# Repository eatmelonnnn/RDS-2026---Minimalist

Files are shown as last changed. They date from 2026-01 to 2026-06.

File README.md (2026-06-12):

# Minimalist Finger

## Assembly Instructions

### 1. Finger Assembly

1. Put bearings into flexion pulleys (3x).
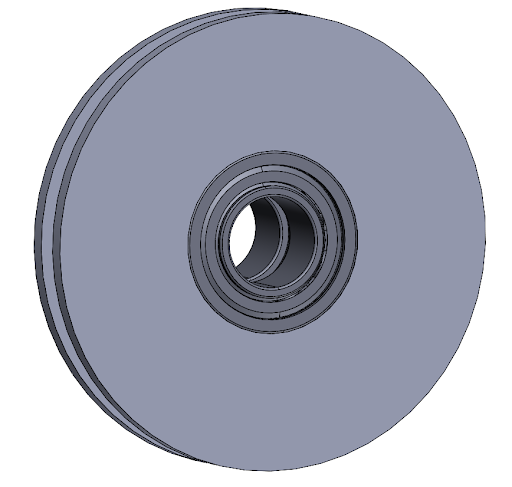
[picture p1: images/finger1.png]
   > 
2. Put bearings and pulleys onto bearing pins (2x).
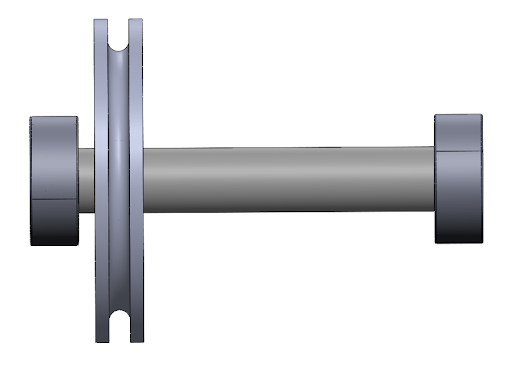
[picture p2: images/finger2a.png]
Step 2a
   > 
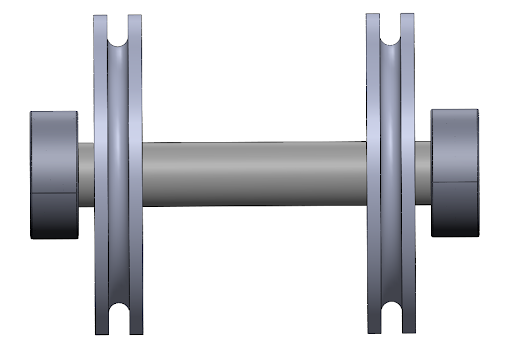
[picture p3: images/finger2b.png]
Step 2b
   > 
3. Tie slipknots onto spring/tendon pins (2x).
4. Snap spring/tendon pin into fingertip and pull tendon into groove.
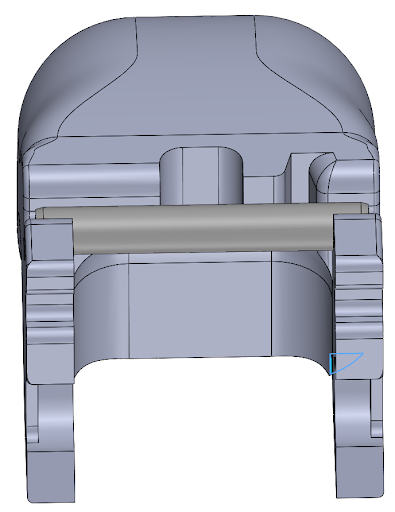
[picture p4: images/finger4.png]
   > 
5. Snap bearing pin into place.
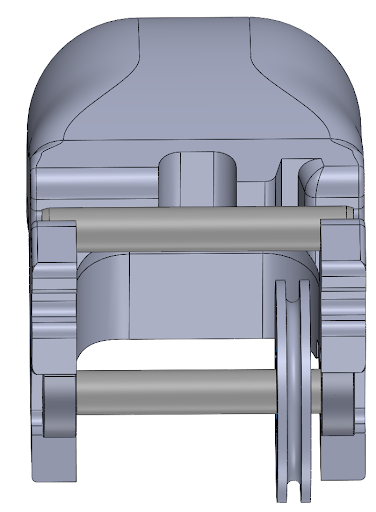
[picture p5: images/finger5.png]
   > 
6. Snap middle linkage onto bearing pin.
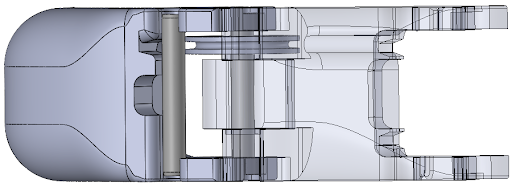
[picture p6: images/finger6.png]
   > 
7. Route tendon through and pull into groove.
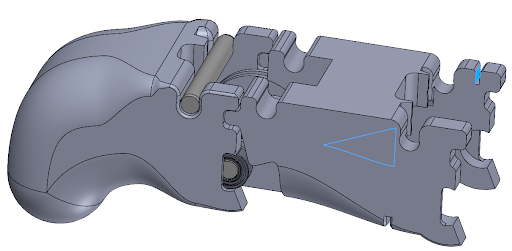
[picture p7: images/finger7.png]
   > 
8. Snap second tendon pin on and pull tendon into groove.
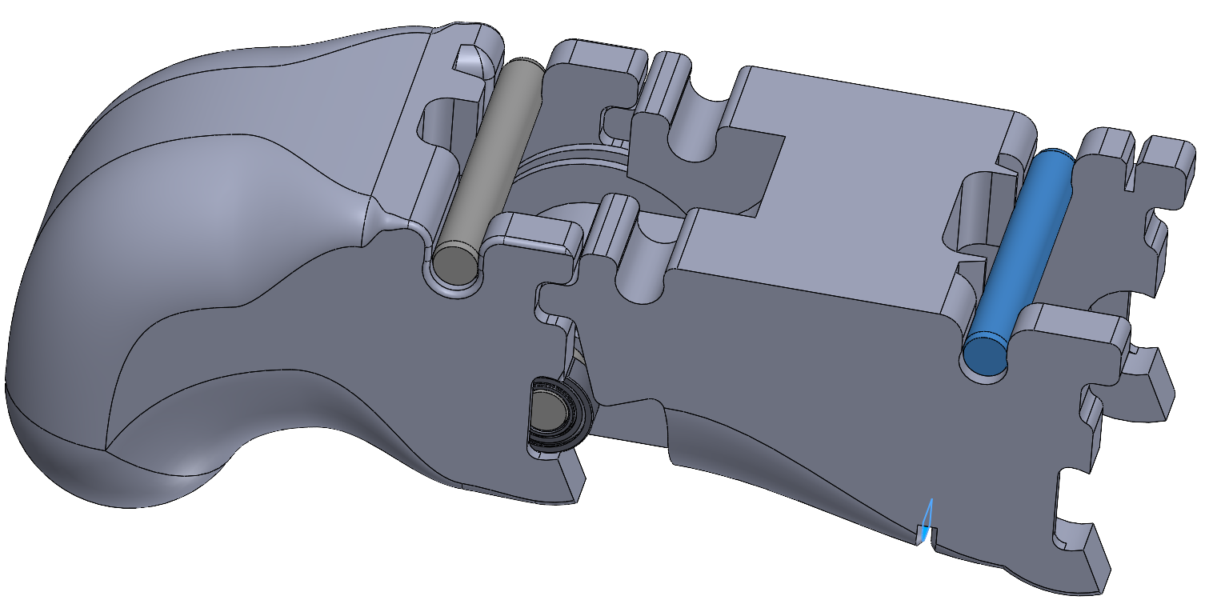
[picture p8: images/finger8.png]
   > 
9. Snap second bearing pin into middle link.
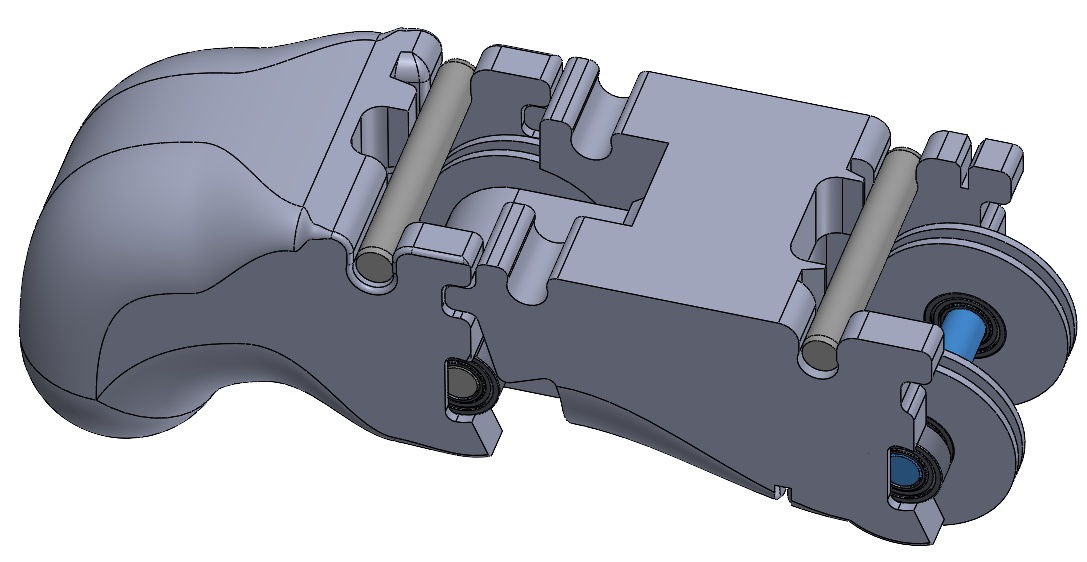
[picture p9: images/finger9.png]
   > 
10. Snap knuckle onto bearing pin.
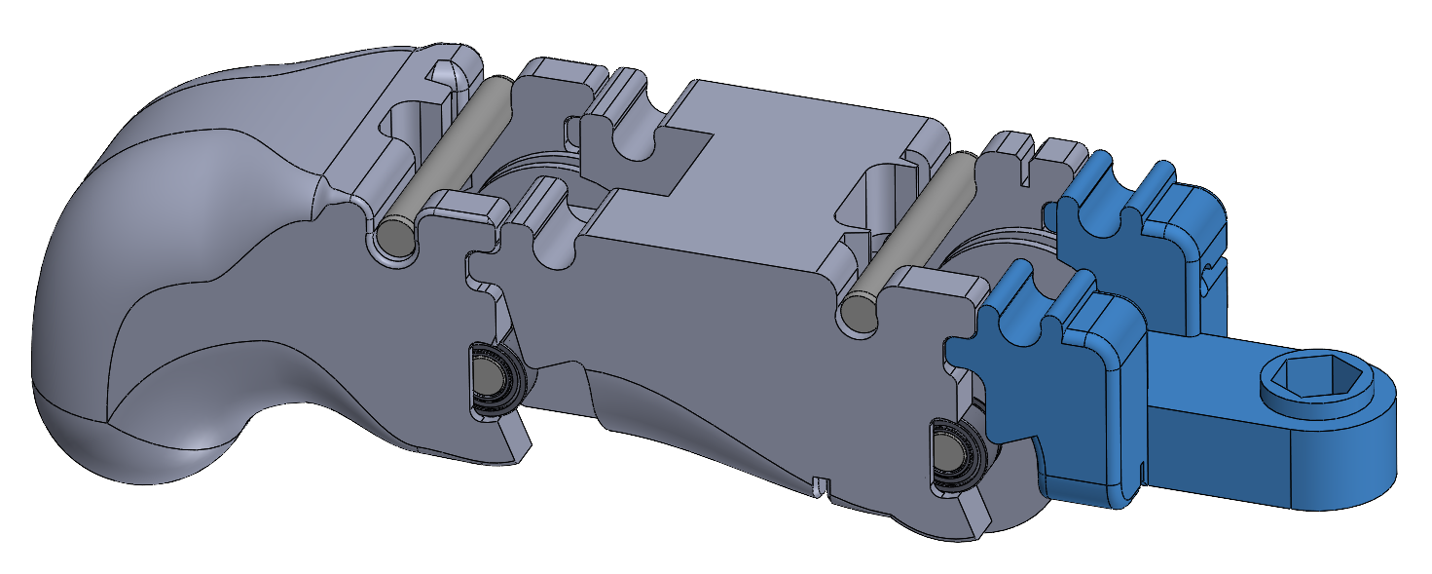
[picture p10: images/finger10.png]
    > 
11. Thread tendons through knuckle and onto grooves.
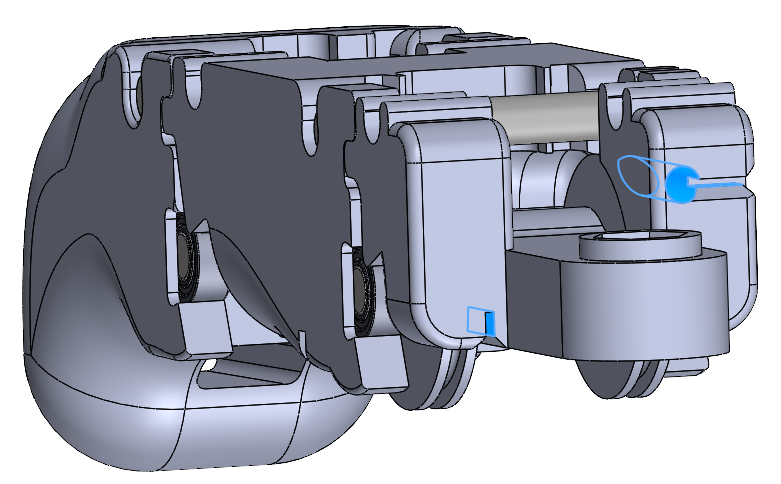
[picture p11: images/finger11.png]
    > 
12. Put bearings into splay pulleys (2x).
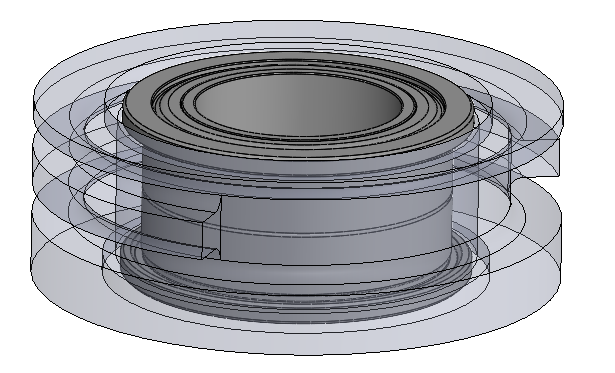
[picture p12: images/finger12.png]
    > 
13. Put belt pulley onto shaft.
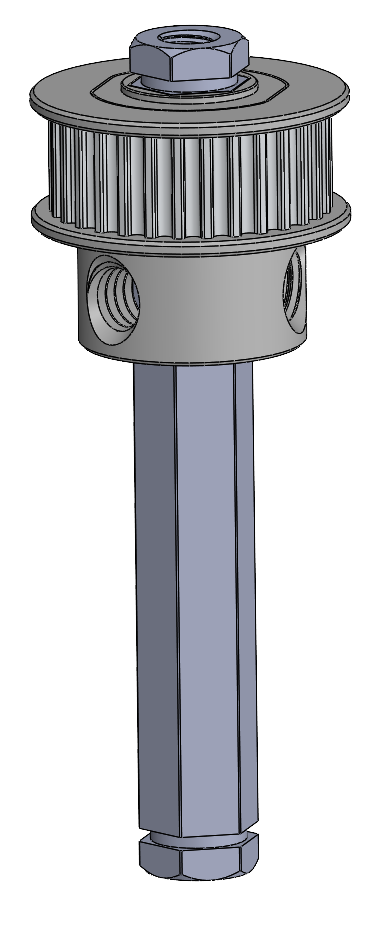
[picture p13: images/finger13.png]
Step 13
    > 
14. Align all splay components and push shaft through.
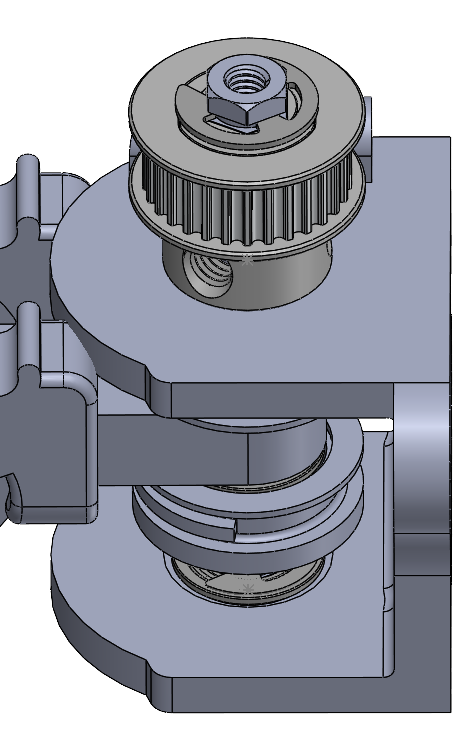
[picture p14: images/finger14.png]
Step 14
    > 
15. Wrap tendons around splay pulleys and thread through base.
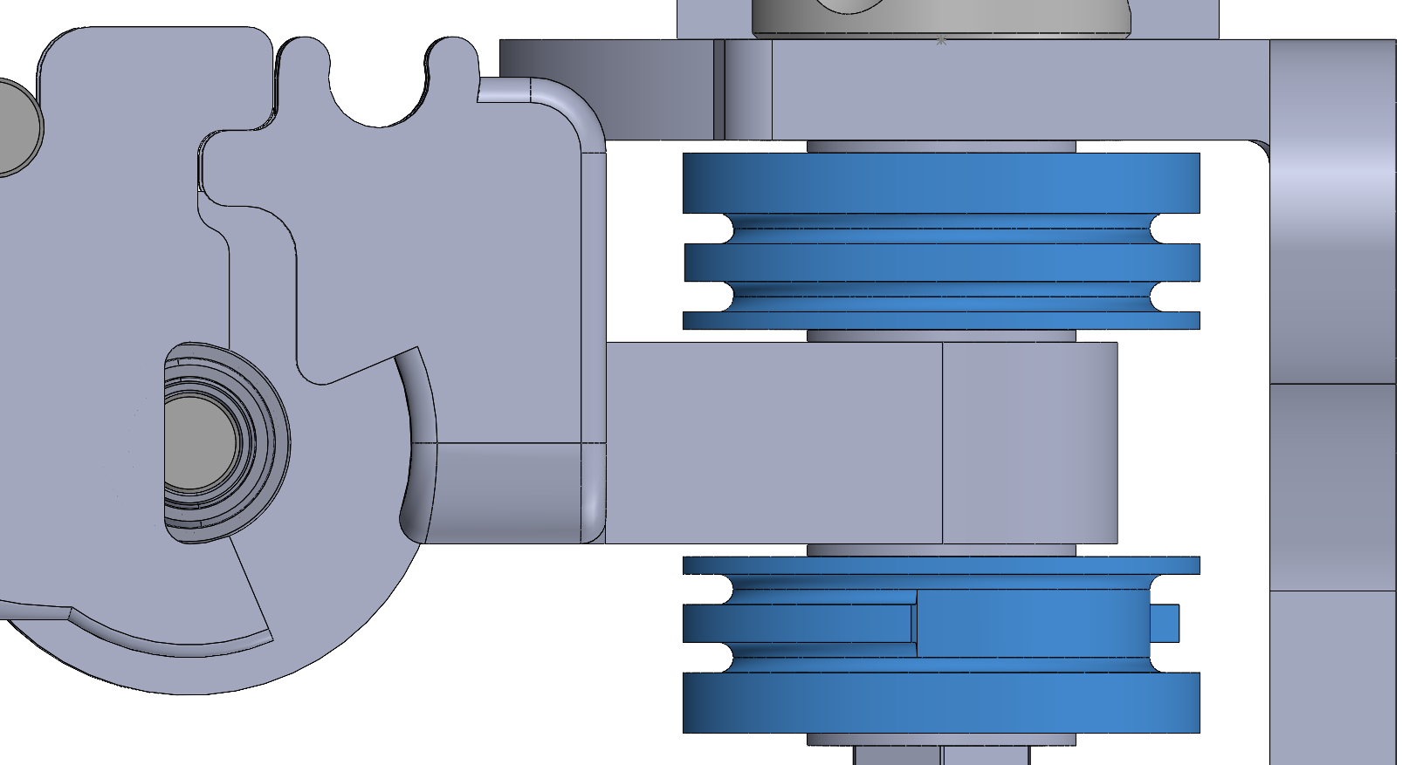
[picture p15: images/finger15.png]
Step 15
    > 
16. Put springs onto pins and snap onto linkages (x2).
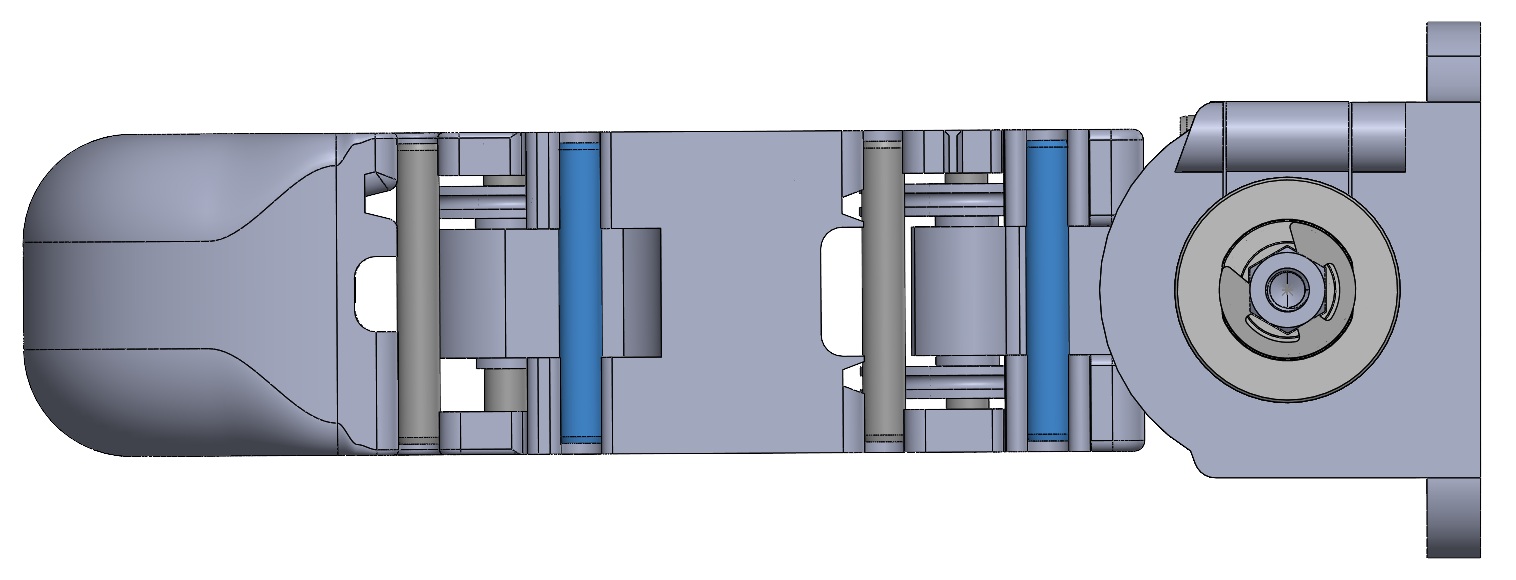
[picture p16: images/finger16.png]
Step 16
    > 
17. Gently pry up tendon/spring pins and loop springs on (x2).
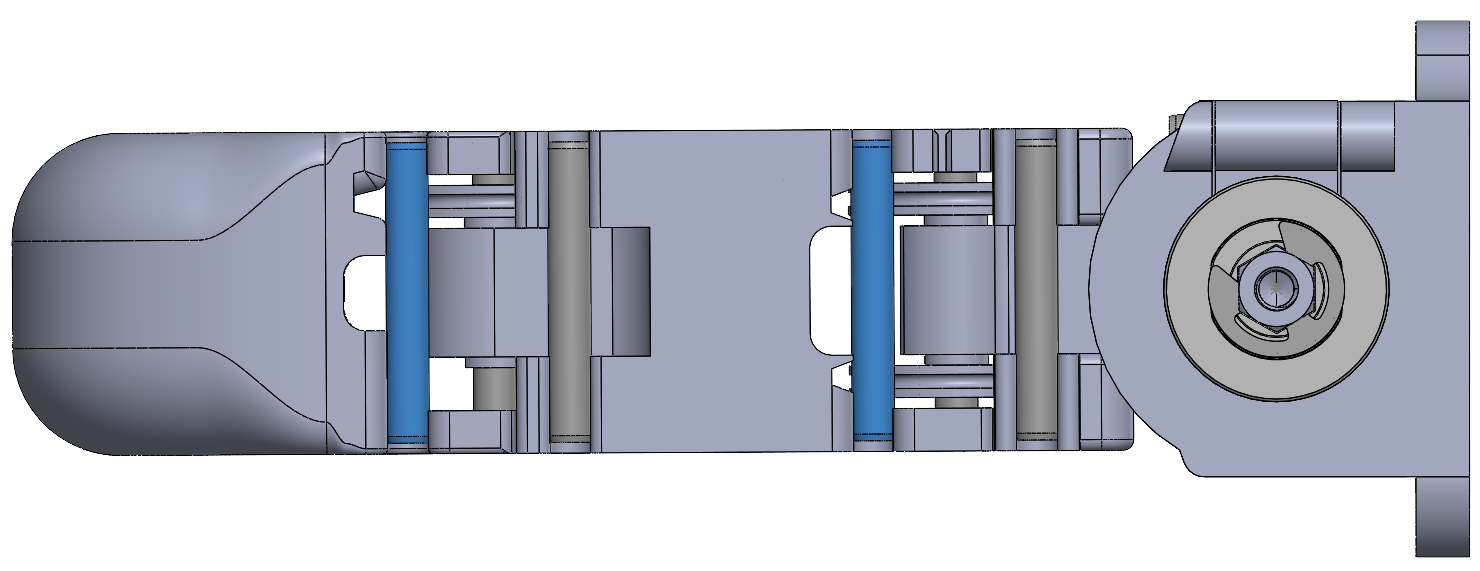
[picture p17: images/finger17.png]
Step 17
    > 

---

##3 2. Mounting Assembly

1. Assemble main 80-20 frame with plates and bolts.
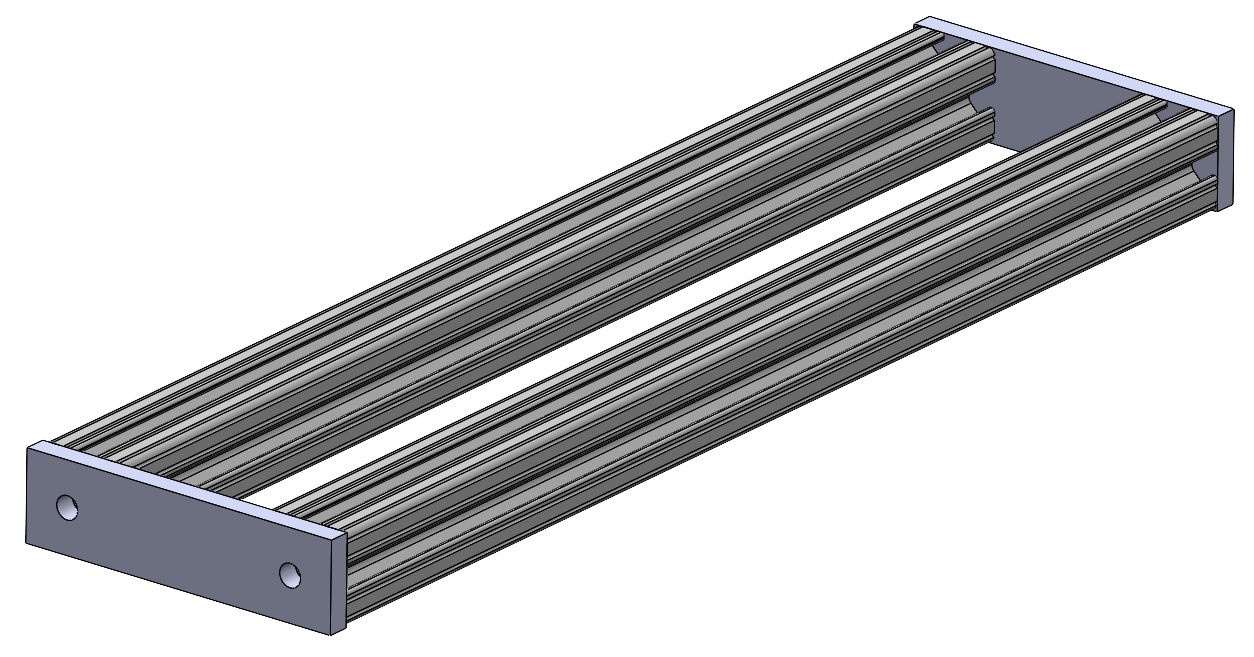
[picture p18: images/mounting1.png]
   > 
2. Put vertical 80-20 on with brackets and bolts.
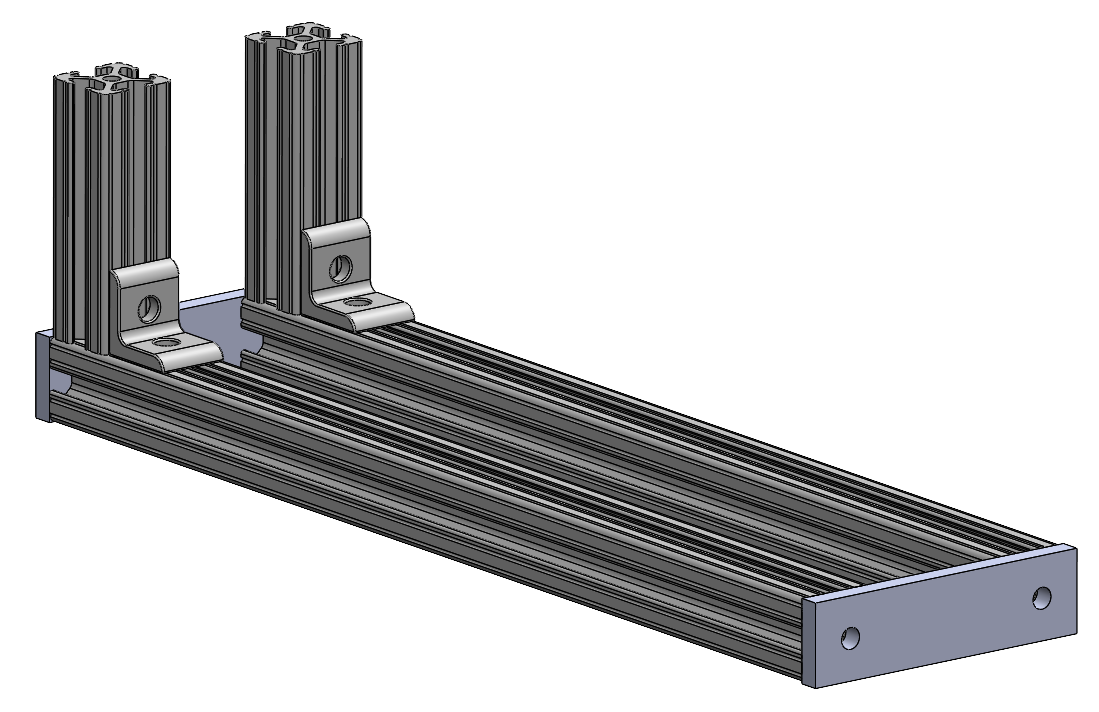
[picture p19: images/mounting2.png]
   > 
3. Put pulley on splay motor.
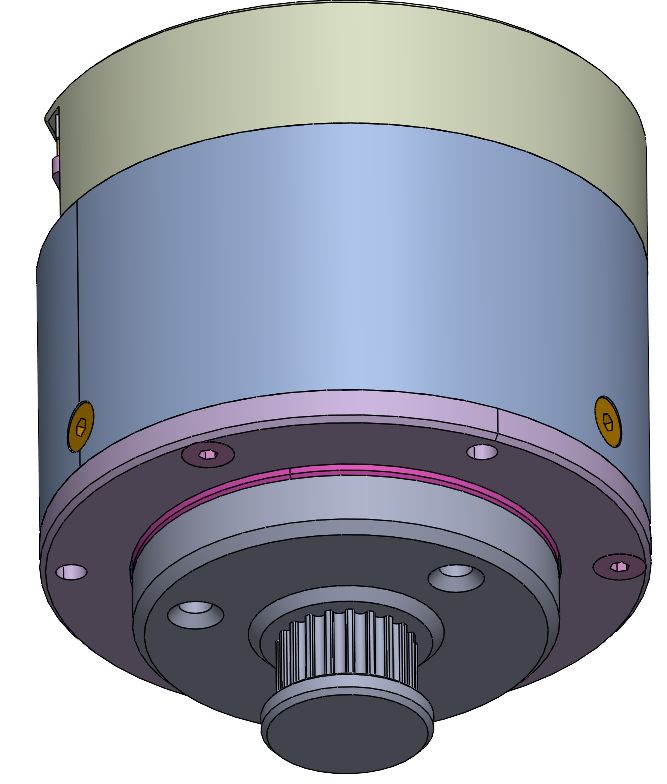
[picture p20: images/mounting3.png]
   > 
4. Put splay motor on splay plate.
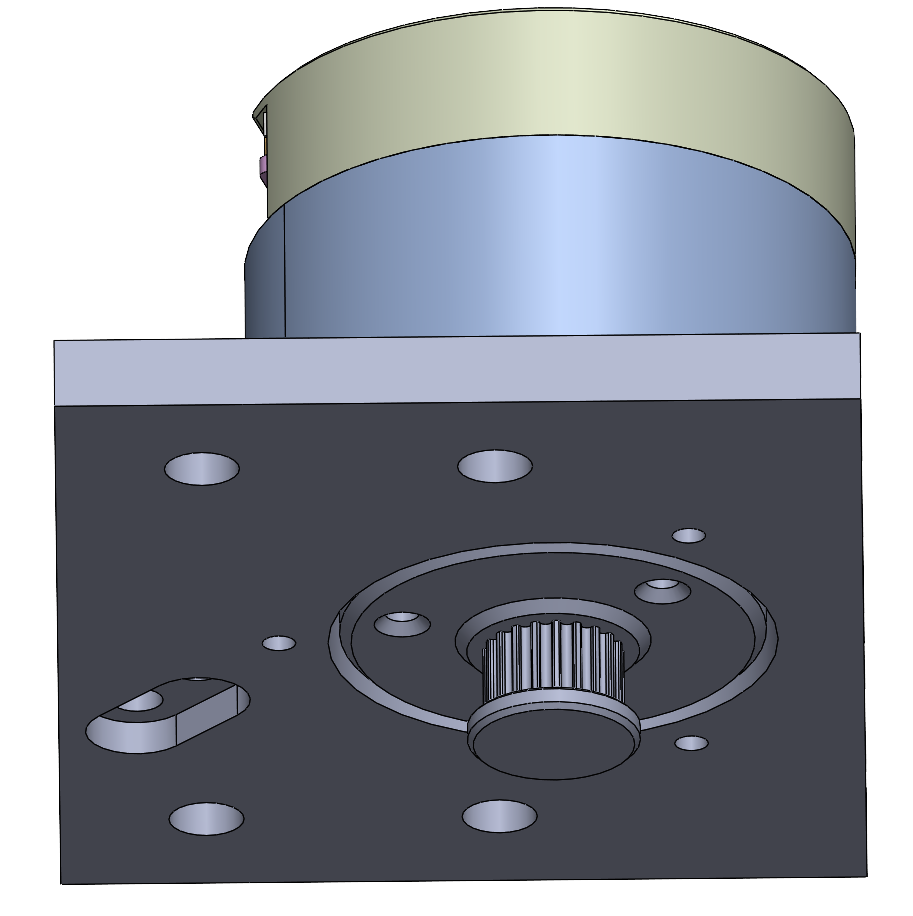
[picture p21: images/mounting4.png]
   > 
5. Put tensioner on splay plate.
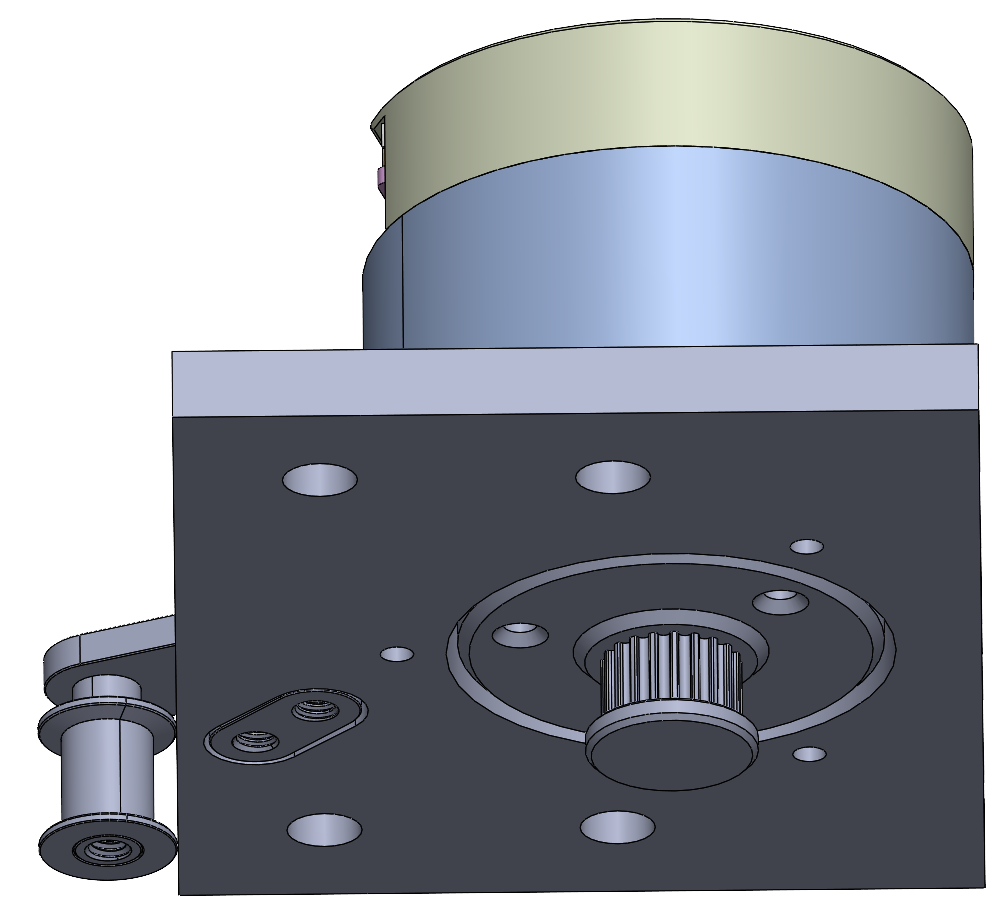
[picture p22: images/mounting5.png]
   > 
6. Put splay plate on vertical 80-20 with brackets and bolts.
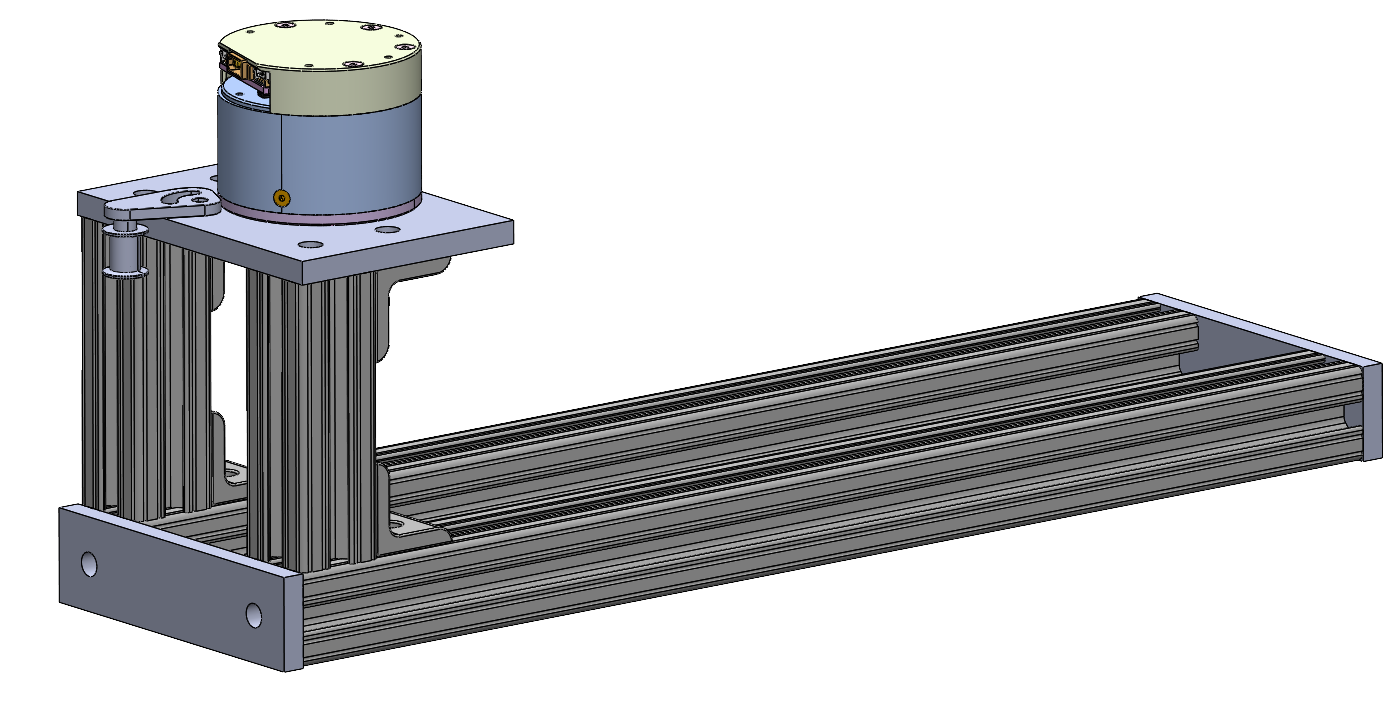
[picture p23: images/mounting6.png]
   > 
7. Put finger plate on vertical 80-20 with bolts.
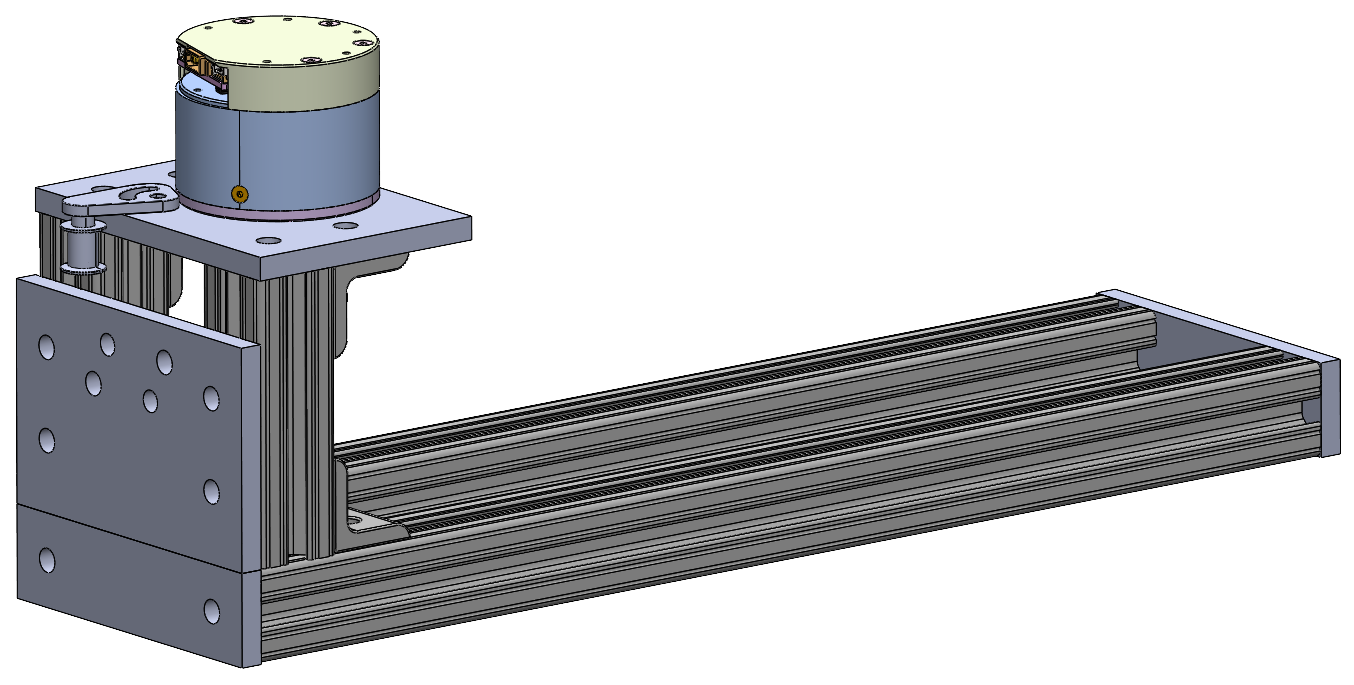
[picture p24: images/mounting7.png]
   > 
8. Put tension plates on 80-20 with bolts (2x).
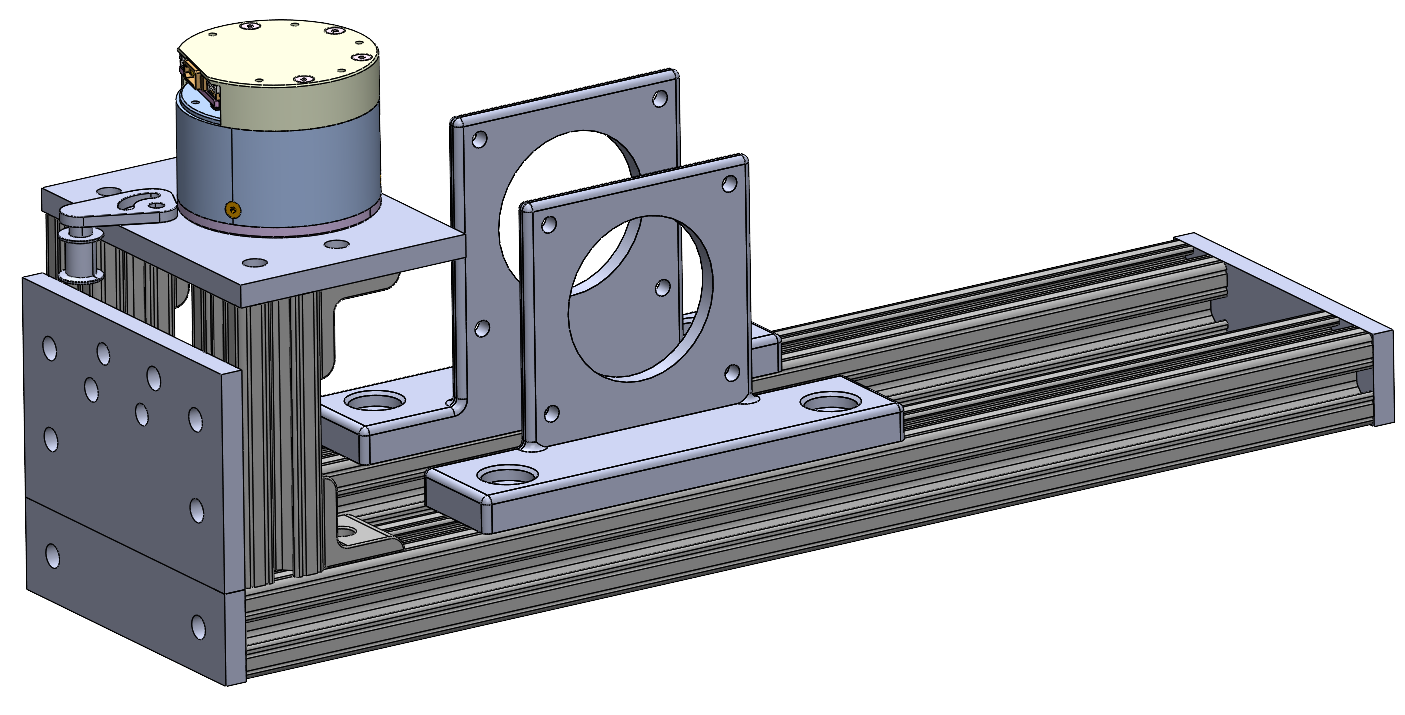
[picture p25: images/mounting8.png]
   > 
9. Put motor plates on 80-20 with bolts (2x).
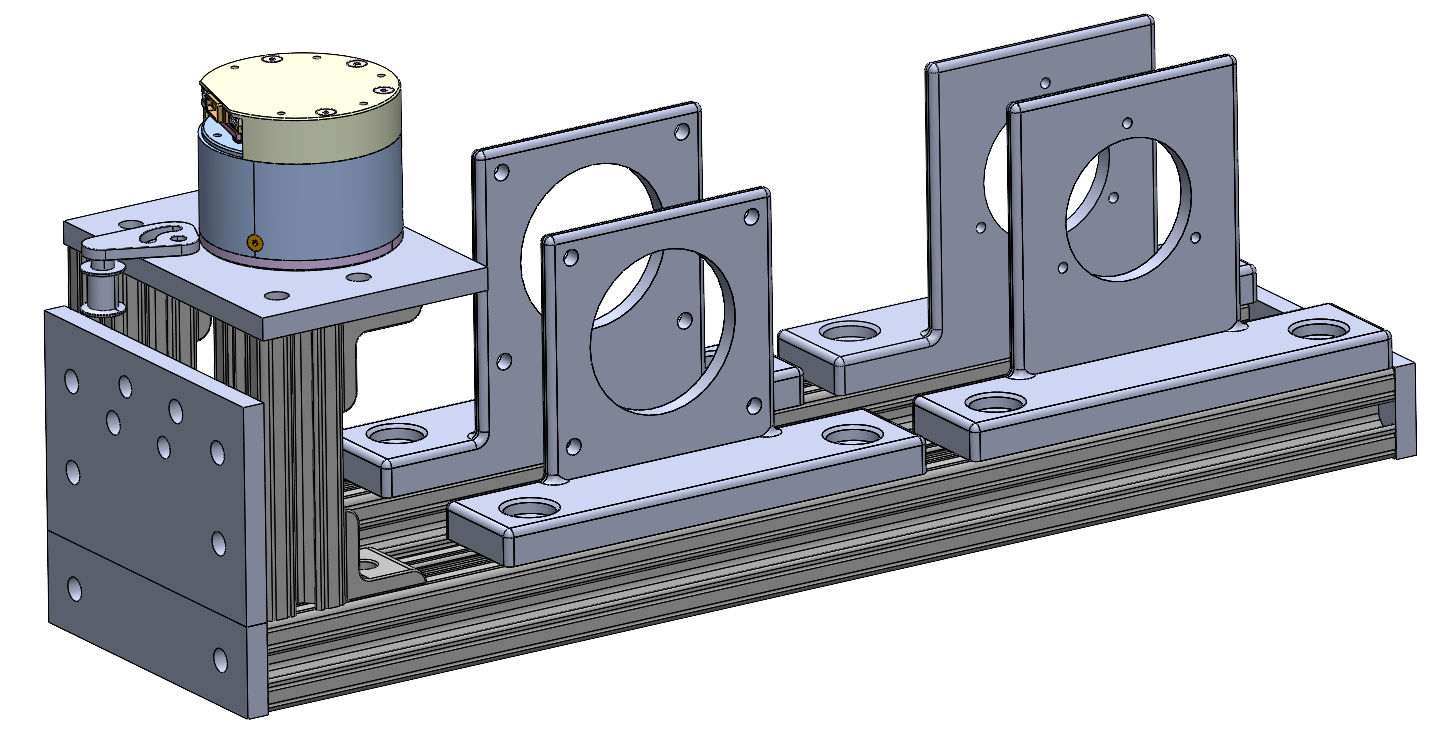
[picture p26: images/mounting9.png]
   > 
10. Put pulleys on flexion motors (2x).
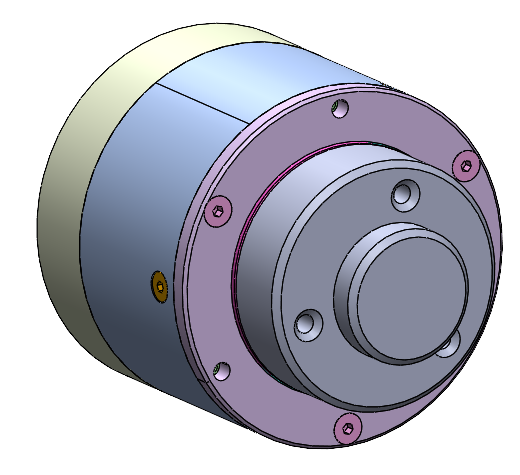
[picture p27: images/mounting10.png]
    > 
11. Put tension sensors on tension plates (2x).
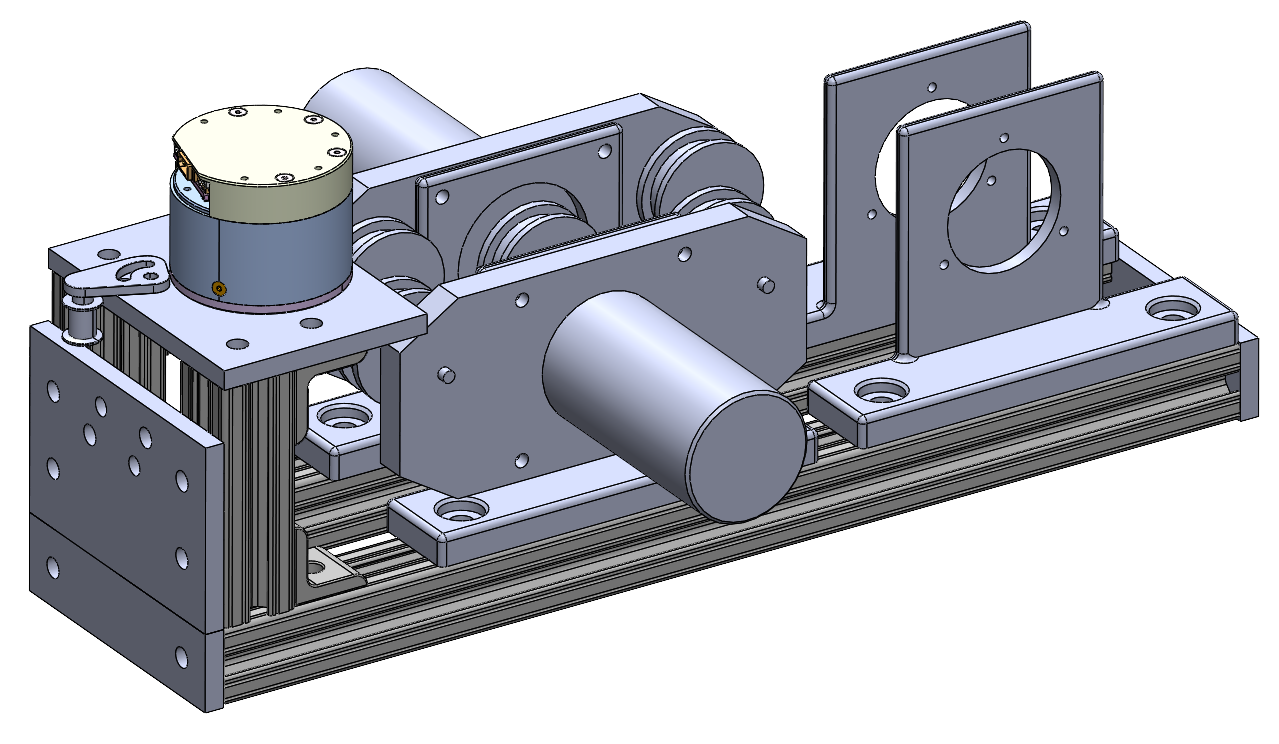
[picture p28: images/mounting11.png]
    > 
12. Put motors on motor plates (2x).
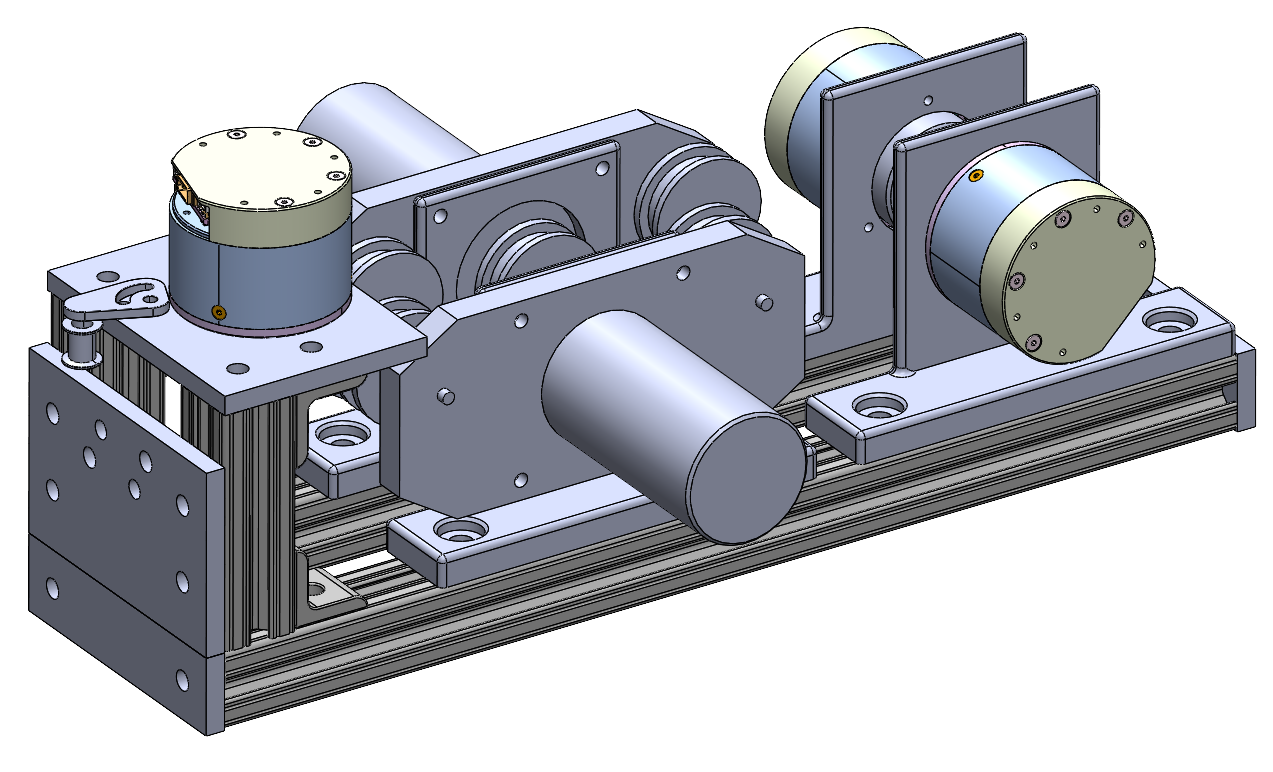
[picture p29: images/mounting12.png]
    > 

---

### 3. Finger/Mounting Integration Assembly

1. Bolt finger onto plate and put splay belt on.
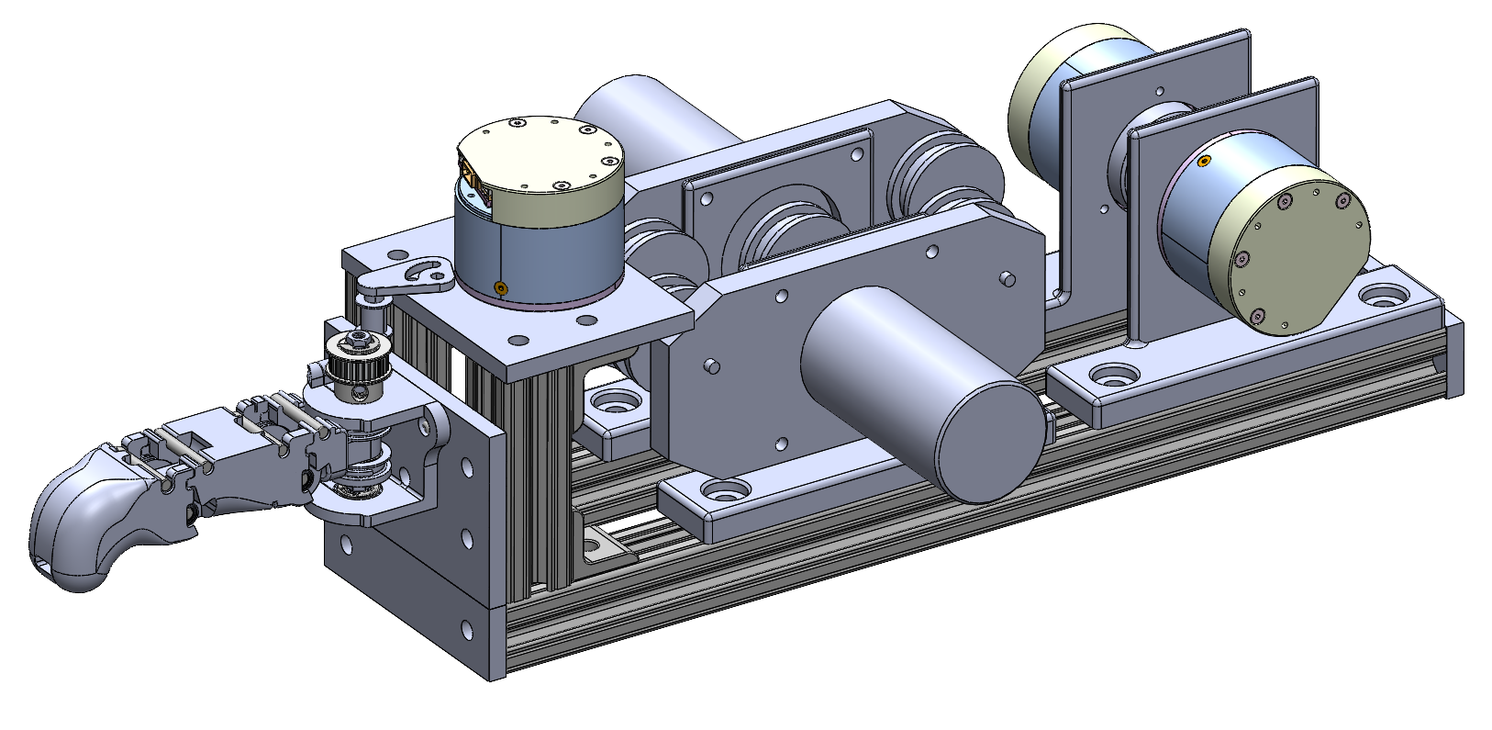
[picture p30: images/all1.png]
   > 
2. Tension splay belt with allen key.
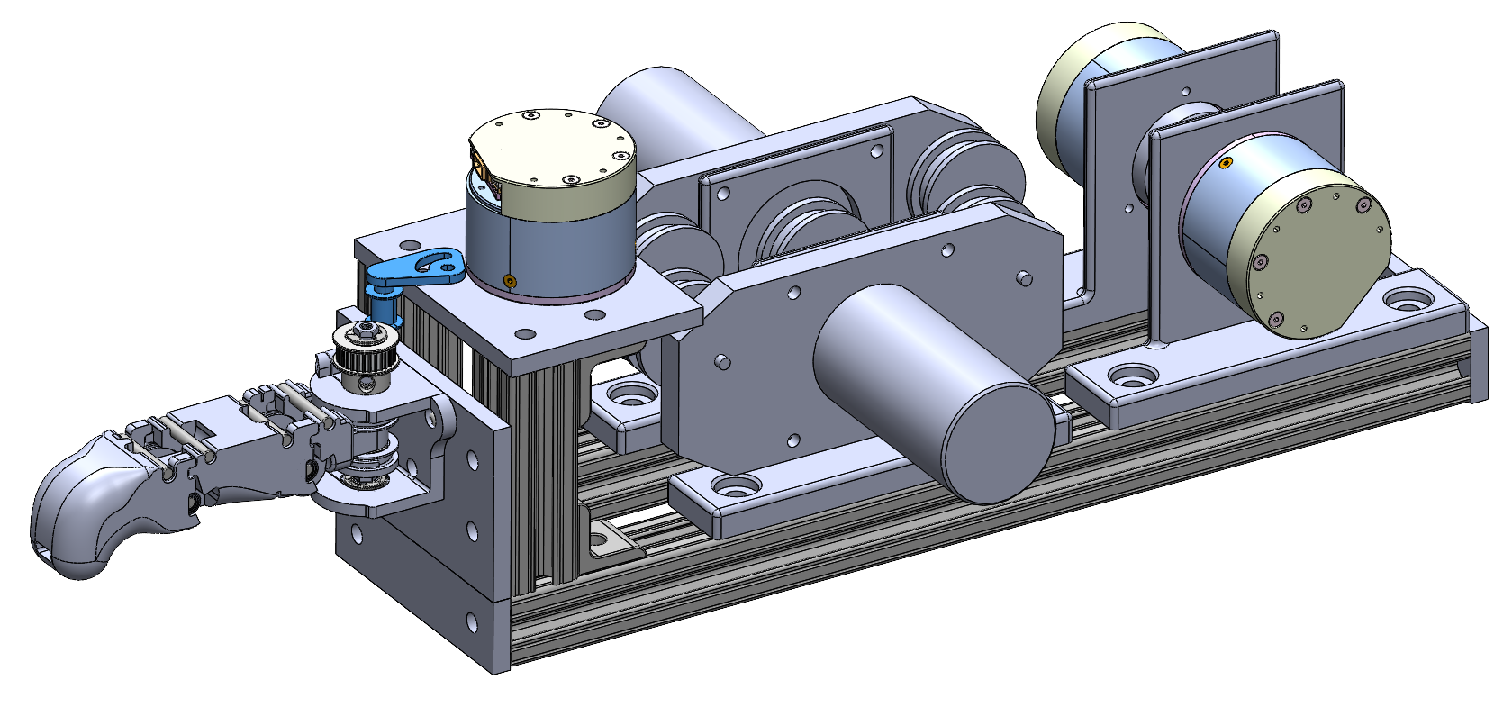
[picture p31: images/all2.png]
   > 
3. Thread tendon from finger through tension sensor and onto pulley.
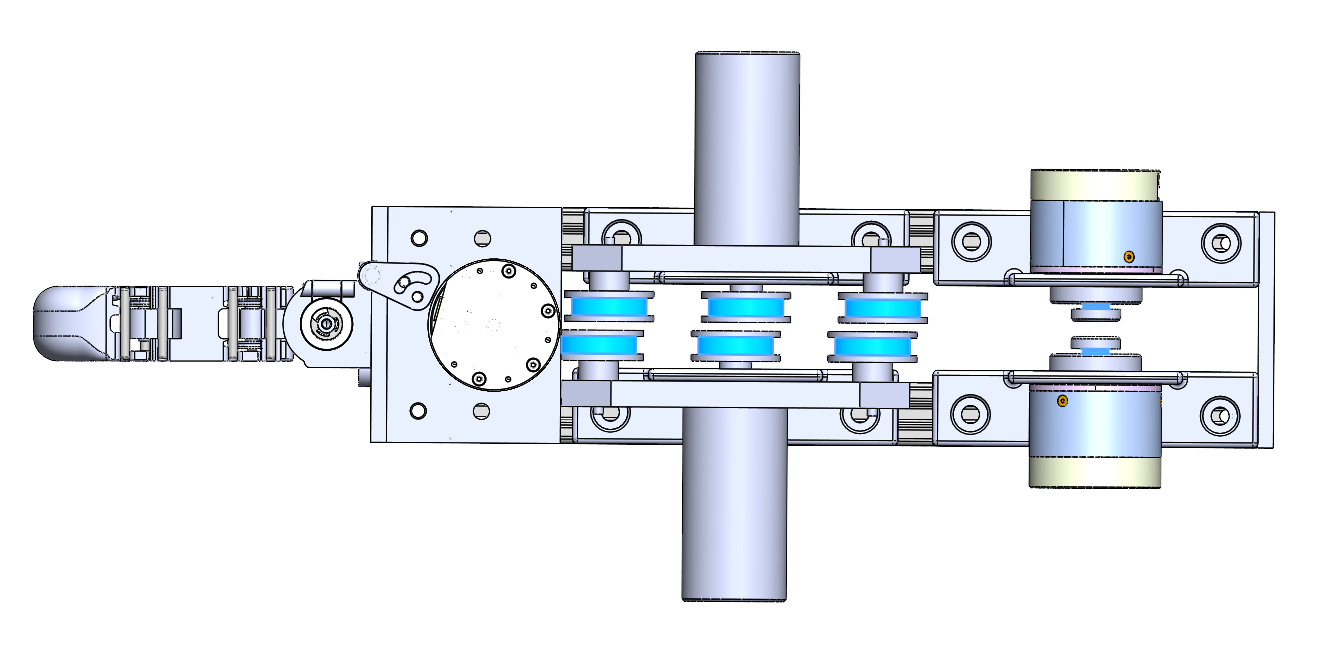
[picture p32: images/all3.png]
   > 
4. Terminate tendon on motor pulley with slipknot and screw.

---
## Instructions to Run Finger Program/Operate Finger Once Assembled

1. Locate main folder in the Electrical and upload `main.ino` to the Teensy 4.1.

2. Let calibration sequence run without interference.

3. Choose desired behavior/test.
   - For all states except the flexion-extension test, simply press the specified button to trigger the state switch.
   - You can switch between any two states by pressing the corresponding buttons.
   - For the MCP flexion-extension test:
     - Move the jumper wire on Pin 33 from **GND** to **3.3V**.
     - This will trigger the flexion-extension test.
     - At this point, there is no way to return to the other states without rerunning the program from the start on the Teensy.

4. When finished, press the **E-stop** to turn off the motors.

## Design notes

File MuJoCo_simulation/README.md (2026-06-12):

# Finger Flick — MuJoCo Simulation

A MuJoCo C++ simulation in which a 3-DOF tendon driven robotic finger actively **flicks a
swinging pendulum**. A ball hangs from a hinged rod and swings back and forth; a
controller watches the rod angle and velocity and, at the right moment, curls the
finger to swat the ball as it approaches. The scene renders in an interactive 3D
window with mouse-controlled camera.

This project uses the **native MuJoCo C/C++ API** with **GLFW** for windowing and
rendering — not the Python bindings.

---

## Contents

| File | Purpose |
|---|---|
| `pendulum_test.cpp` | Simulation loop, controller state machine, and GLFW/MuJoCo rendering. |
| `test.xml` | MuJoCo MJCF model: the finger, the pendulum, actuators, and a start keyframe. |
| STL meshes | `base_link.STL`, `splay_link.STL`, `mcp_link.STL`, `pip_link.STL` can be accessed in the MuJoCo_simulation/finger_workspace/src/finger_description/meshes directory. |

---

## What the simulation does

### The model (`test.xml`)

The world contains two independent mechanisms:

**1. The finger** — a serial chain of three actuated joints mounted to a fixed base:

- `splay_joint` — sideways spread (axis Z), sprung and damped, held at 0 by the controller.
- `mcp_joint` — the "knuckle" (MCP), range ±1.57 rad.
- `pip_joint` — the middle joint (PIP), range ±1.57 rad. The PIP link carries a
  capsule collision geom (`pip_geom`) — this is the part that actually strikes the ball.

Each joint is driven by a MuJoCo **`position` actuator** with a proportional/derivative
gain (`kp`/`kv`), so writing a target angle to `d->ctrl[i]` servos that joint toward it.

**2. The pendulum** — a non-colliding support box with a hinged rod hanging below it
and a sphere (`ball_geom`) at the rod's tip. The hinge is almost frictionless
(`damping="0.00025"`), so once released it swings freely under gravity.

Other model settings worth knowing:

- Gravity `-9.81`, timestep `0.001 s`, implicit integrator, contact enabled.
- A keyframe named **`start`** sets the initial pose `qpos = "0 0 0 -1.4"`
  (splay, MCP, PIP at 0; rod pulled back to −1.4 rad so it swings in on release).
- Contact parameters (`solref`, `solimp`, `friction`) are tuned on `pip_geom` and
  `ball_geom` so the strike reads as a crisp swat.

The generalized coordinates are, in order:
`qpos[0]=splay`, `qpos[1]=MCP`, `qpos[2]=PIP`, `qpos[3]=rod hinge`.

### The controller (`pendulum_test.cpp`)

The main loop steps the physics once per iteration (and sleeps to keep the sim
roughly real-time), reads joint states, then runs a three-state machine that drives
the finger:

- **READY** — finger held open. It waits until the rod swings past a trigger angle
  while moving toward the finger, then transitions to FLICK.
- **FLICK** — commands the MCP and PIP joints to curl (targets `0.8` and `1.2` rad)
  for a short burst (~0.1 s) to swat the ball.
- **RESET** — returns the finger to open and holds for ~0.4 s before re-arming.

Alongside the state machine, the loop checks `d->contact[...]` every step for a
collision between `pip_geom` and `ball_geom` to flag when an actual hit occurs.
Every 50 steps it prints the current state, rod angle/velocity, and joint angles to
the console; every 10 steps it redraws the window.

> **Tuning:** the trigger angle, approach-velocity threshold, flick/reset durations,
> and the curl targets are all `const` knobs near the top of the loop. Adjust them
> while watching the printed `Rod` values to dial in the timing for your build.

### Interactive controls

| Input | Action |
|---|---|
| Left-drag | Rotate camera |
| Right-drag | Pan camera |
| Shift + drag | Alternate rotate/pan axis |
| Scroll | Zoom |
| Esc | Quit |

---

## Prerequisites

- A C++17 compiler (GCC, Clang, or MSVC).
- **MuJoCo** (the C/C++ library). Version 3.x is recommended — see install below.
- **GLFW 3** development libraries.
- **OpenGL** (present on essentially all desktop systems).
- **CMake** ≥ 3.16 (recommended for the build).

---

## Installing MuJoCo

MuJoCo is open source (Apache-2.0, maintained by Google DeepMind). For C/C++ work the
easiest route is the **prebuilt library release** — there is no installer; it ships as
a single archive (`.tar.gz` on Linux, `.dmg` on macOS, `.zip` on Windows).

1. Go to the MuJoCo GitHub releases page:
   <https://github.com/google-deepmind/mujoco/releases>
2. Download the latest release for your platform (3.2.7 or newer at time of writing).
3. Extract it somewhere stable, e.g. `~/.mujoco/mujoco-3.x.x/`. You should end up with
   `include/` (headers) and `lib/` or `bin/` (the shared library).

> If you prefer, you can also build MuJoCo from source (needs CMake + a C++17
> compiler), but the prebuilt library is recommended unless you intend to modify
> MuJoCo's core.

### GLFW

- **Ubuntu/Debian:** `sudo apt install libglfw3-dev`
- **macOS (Homebrew):** `brew install glfw`
- **Windows:** download from <https://www.glfw.org/> or install via `vcpkg install glfw3`.

---

## Project layout and file paths

⚠️ **The paths in the source are relative and must line up, or the model won't load.**

- `pendulum_test.cpp` loads the model from `../../finger_description/urdf/test.xml`.
- `test.xml` in turn references its meshes at `../meshes/*.STL`.

So the model and meshes are expected to live like this, with the executable run from a
directory **two levels below** the parent of `finger_description/`:

```
project/
├── finger_workspace/
│   ├── urdf/
│   │   └── test.xml
│   └── meshes/
│       ├── base_link.STL
│       ├── splay_link.STL
│       ├── mcp_link.STL
│       └── pip_link.STL
└── finger_controller/
    └── pendulum_test     # run from here → ../../finger_description/urdf/test.xml
```

If your layout differs, either move the files to match, or edit the path in the
`mj_loadXML(...)` call (and the mesh paths in `test.xml`) accordingly. Using absolute
paths while you get it running first is a reasonable shortcut.

---

## Building

### Option A — CMake (recommended)

Create a `CMakeLists.txt` next to `pendulum_test.cpp`:

```cmake
cmake_minimum_required(VERSION 3.16)
project(finger_flick CXX)

set(CMAKE_CXX_STANDARD 17)
set(CMAKE_CXX_STANDARD_REQUIRED ON)

# Point this at your extracted MuJoCo directory
set(MUJOCO_DIR "$ENV{HOME}/.mujoco/mujoco-3.2.7" CACHE PATH "MuJoCo root")

find_package(glfw3 REQUIRED)
find_package(OpenGL REQUIRED)

add_executable(pendulum_test pendulum_test.cpp)

target_include_directories(pendulum_test PRIVATE
    ${MUJOCO_DIR}/include
    ${CMAKE_CURRENT_SOURCE_DIR})      # so kinematics.h is found

target_link_directories(pendulum_test PRIVATE ${MUJOCO_DIR}/lib)

target_link_libraries(pendulum_test PRIVATE
    mujoco
    glfw
    OpenGL::GL)
```

Then build:

```bash
mkdir -p build && cd build
cmake .. -DMUJOCO_DIR=/path/to/mujoco-3.2.7
cmake --build .
```

### Option B — direct compile (Linux)

```bash
g++ -std=c++17 pendulum_test.cpp -o pendulum_test \
    -I/path/to/mujoco/include -I. \
    -L/path/to/mujoco/lib -lmujoco -lglfw -lGL
```

On Linux you may also need the library on the loader path at runtime:

```bash
export LD_LIBRARY_PATH=/path/to/mujoco/lib:$LD_LIBRARY_PATH
```

(macOS uses `DYLD_LIBRARY_PATH`; on Windows, place `mujoco.dll` next to the
executable or add its folder to `PATH`.)

---

## Running

From the directory that makes the relative model path resolve (see **Project layout**):

```bash
./pendulum_test
```

You should see:

- A console message confirming the `start` keyframe loaded.
- A 3D window with the floor, the finger, and the swinging ball pendulum.
- Periodic console output like:

  ```
  State: READY  | Rod: -1.182 (vel 0.642) | MCP: 0.000 PIP: 0.000
  Ball approaching = 1
  ```

The ball swings in, the finger flicks, and the loop re-arms. Drag with the mouse to
orbit the camera; press **Esc** to quit.

---

## Troubleshooting

- **`Error loading model: ...`** — the XML path or a mesh path is wrong. Confirm the
  directory layout above, or hard-code an absolute path in `mj_loadXML`.
- **`Keyframe not found`** — the model loaded but the `start` key is missing or renamed;
  the sim still runs, just from the default pose.
- **Linker errors for `mj_*` / `mjv_*` / `mjr_*`** — MuJoCo include/lib paths are wrong,
  or `-lmujoco` is missing.
- **Linker errors for `glfw*`** — GLFW dev package not installed or not linked.
- **`cannot open shared object file: libmujoco...`** at runtime — set
  `LD_LIBRARY_PATH` (Linux) / `DYLD_LIBRARY_PATH` (macOS), or put the DLL beside the
  exe (Windows).
- **`kinematics.h: No such file or directory`** — supply that header and make sure its
  directory is on the include path (`-I.` or `target_include_directories`).
- **The finger never flicks / always misses** — tune `flick_trigger_angle`, the
  `rod_vel` threshold, and `flick_duration` while watching the printed `Rod` values.

---

## Notes & references

- MuJoCo docs: <https://mujoco.readthedocs.io/>
- MuJoCo releases: <https://github.com/google-deepmind/mujoco/releases>

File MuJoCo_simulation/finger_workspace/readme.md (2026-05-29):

### Opening mujoco viewer
1. Ensure you are in the folder that contains finger.xml
2. python3 -m mujoco.viewer --mjcf=finger.xml

## Run virtual environmnent
source /mujoco_env/bin/activate     # have to create in that directory first

## Check STL number of faces
python3 -c "
from stl import mesh
import os

for f in os.listdir('.'):
    if f.endswith('.STL') or f.endswith('.stl'):
        m = mesh.Mesh.from_file(f)
        print(f'{f}: {len(m.vectors)} faces')
"

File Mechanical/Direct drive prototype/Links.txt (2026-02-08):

Spiral bevel gear: https://catalog.khkgears.us/item/bevel-gears/spiral-bevel-gears-sbs/sbs1-4020r
Spiral bevel pinion: https://catalog.khkgears.us/item/bevel-gears/spiral-bevel-gears-sbs/sbs1-2040l

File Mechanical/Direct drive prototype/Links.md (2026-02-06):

1. **maxon for motor selection:**

https://www.maxongroup.us/maxon/view/category?\_gl=1\*1xv3u2h\*\_gcl\_au\*MTE0MzA2OTMzNC4xNzY4NDEwNjE2\*\_ga\*NTQzNzM2MDA3LjE3Njg0MTA2MTc.\*\_ga\_TKST59FCFB\*czE3Njg0MTA2MTYkbzEkZzEkdDE3Njg0MTA2NTkkajE3JGwwJGgw

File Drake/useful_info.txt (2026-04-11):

Open virtual environment:
-------------------------
- open ubuntu 22.04
- got to base directory cd /
- run: source /drake_env/bin/activate     (exit -> to deactivate)

Convert from obj to sdf:
-----------------------
- make sure you are in the virtual environment
- to get more details run: python3 -m pydrake.multibody.mesh_to_model --help
- run: python3 -m pydrake.multibody.mesh_to_model path/to/mesh.obj (basic no mass specification)
- note if scale used is not meters, you have to specify scale
- variables that can be specified: 
	- mesh_to_model.py [-h] [--model-name NAME] [--scale FACTOR] [--density KG/M3 | --mass KG] 
			[--origin-at-com | --body-origin X,Y,Z]
                        [--package ENCODING] [--output-dir OUTPUT_DIR]
                        mesh_path
- Note: I got an error when I used a 0.001 scale for mm so for now just ignore scale

Drake PID Controller:
--------------------
2 inputs: desired state, estimated state
1 output: control signal (fed into the plant)

Control signal: y = p_y*(kp*(qd-qc) + kd*(vd-vc)+ ki*integral(qd-qc))
		qd: desired position
		qc: controlled position
		vd: desired velocity
		vc: controlled velocity

Changes made to assembly:
--------------------
The main assembly of the finger is fully represented in the simulation, only spacers and retainers are not included due to their small weight and minimal influence to the system.

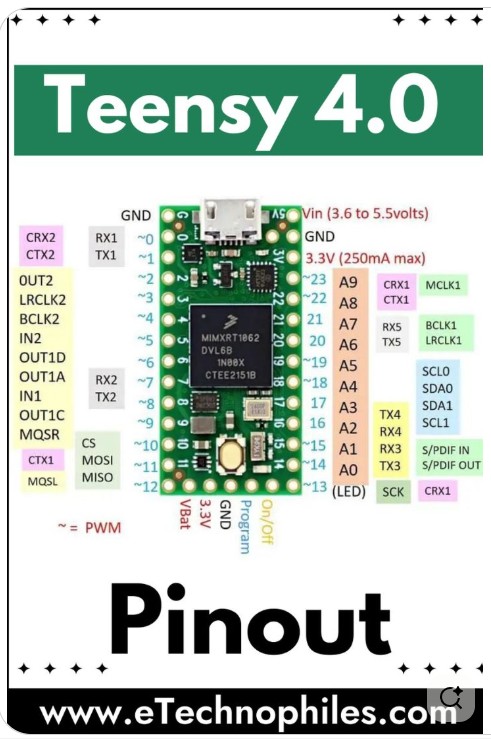
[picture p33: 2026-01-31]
Electrical/Warmup Project/Electrical Diagrams/Circuit diagrams kicad/Teensy_pinout.jpg

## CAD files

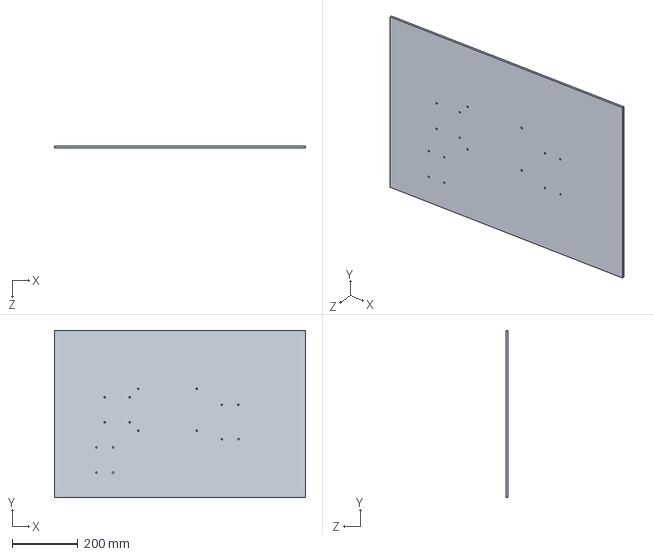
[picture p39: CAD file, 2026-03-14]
Mechanical/Full assembly parts/base_plate_full_assembly.SLDPRT
762.0 x 508.0 x 6.00 mm

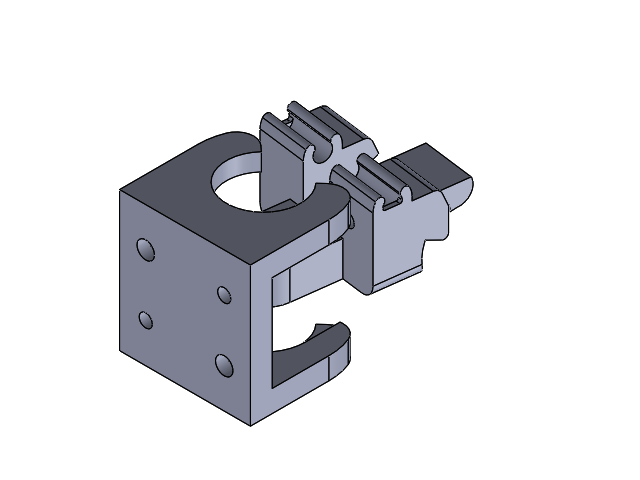
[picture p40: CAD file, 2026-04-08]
Drake/minimalist finger sldrt/Assem1.SLDASM
FingerBase
FingerMCP

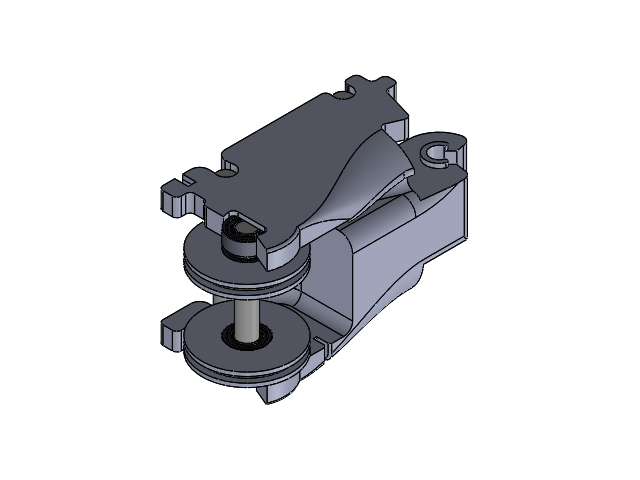
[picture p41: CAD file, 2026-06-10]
Mechanical/Assemblies/Link parts for simulation/mcp_flexion.SLDASM
FingerLinkExperimental_1
inner_ring_71 x 4
outer_ring_172 x 4
bearing_ball_65 x 36
sheild_67 x 8
metal_cage_56 x 4
_001_miniature_ball_bearing_inch x 4
91585A465_18-8 Stainless Steel Dowel Pin_1 x 3
Flexion Tendon Pulley Spacer_1 x 2
Flexion Tendon Pulley_1 x 2

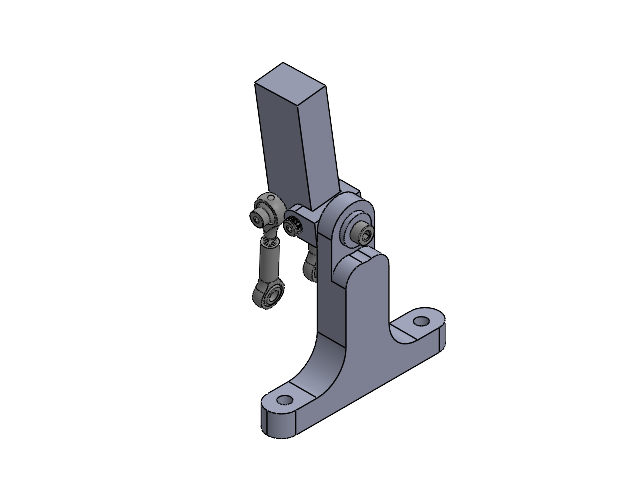
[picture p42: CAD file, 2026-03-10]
Mechanical/Finger Prototype/Proto-Finger Assembly.SLDASM
MCP Diff Joint Connector
Proximal Phalange
59935K12_Ball Joint Rod End x 2
4mm ID, 10 mm OD V-Groove Bearing
92981A745_Alloy Steel Shoulder Screws
MCP Joint Stand
59935K14_Ball Joint Rod End x 2
94459A150_Heat-Set Inserts for Plastic.step
Abduction Joint Constraint Washer
91290A139_Black-Oxide Alloy Steel Socket Head Screw
94361A588_Short-Thread Alloy Steel Shoulder Screw
90695A033_Medium-Strength Steel Thin-Profile Hex Nut x 2

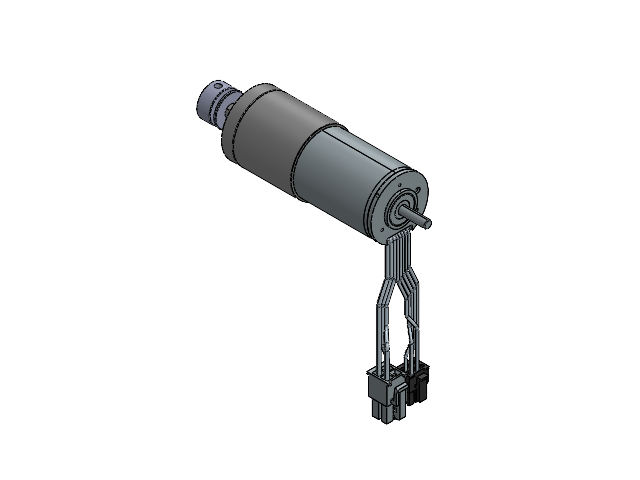
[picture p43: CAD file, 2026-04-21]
Mechanical/Flexion Motor/Assem1.SLDASM
539481_EC-i30_45W_HighTorque.stp
166933_GP32C-2st
Flexion Pulley v2

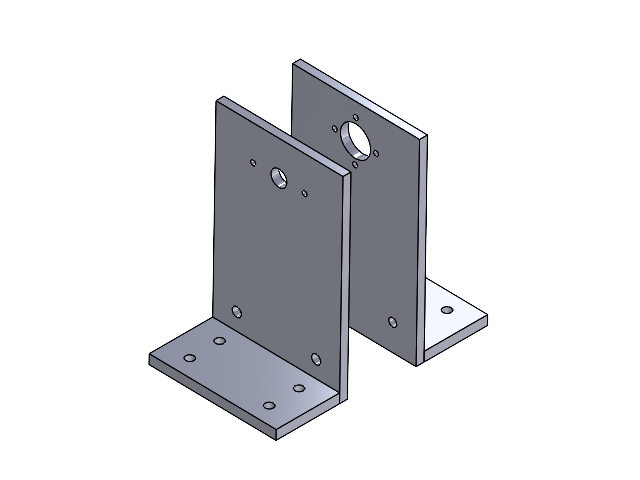
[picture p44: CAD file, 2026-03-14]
Mechanical/Full assembly parts/mcp_assembly_motor_side.SLDASM
base_mcp_support1 x 2
mcp_vertical_support1
mcp_vertical_support2

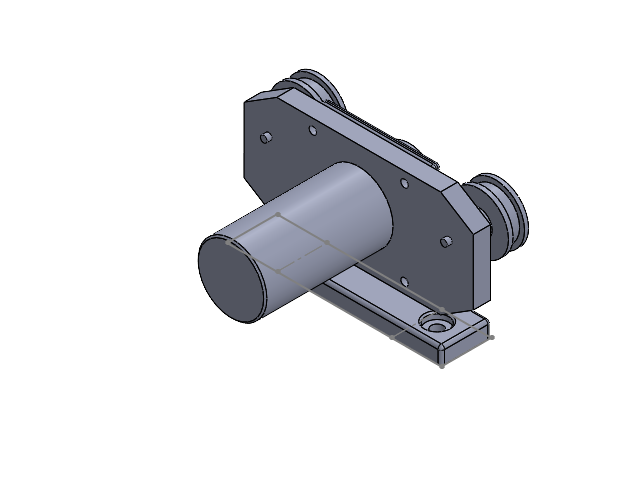
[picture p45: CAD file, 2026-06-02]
Mechanical/Load Cell Assembly/MCPTensionSensorAssembly.SLDASM
3_pulley_tension_load_cell
TensionMountLeft

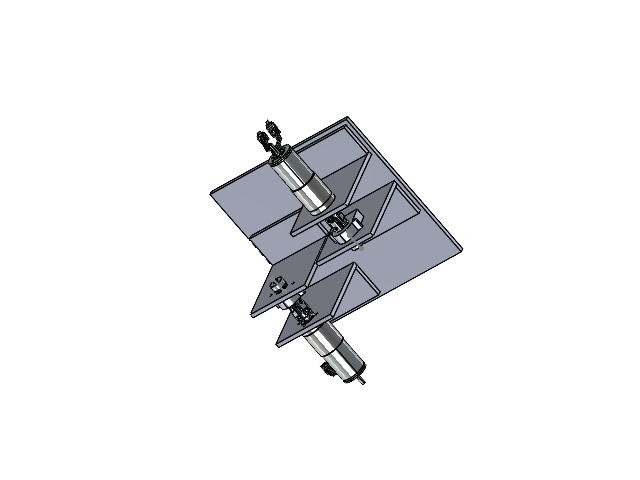
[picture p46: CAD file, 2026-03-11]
Mechanical/motor_mounts/motors_assembly.SLDASM
base_plate
base_mcp_support1 x 4
mcp_vertical_support1
pip_vertical_support1
pip_vertical_support2
7804K111_Stainless Steel Ball Bearing x 2
mcp_vertical_support2
Encoder Replica x 2

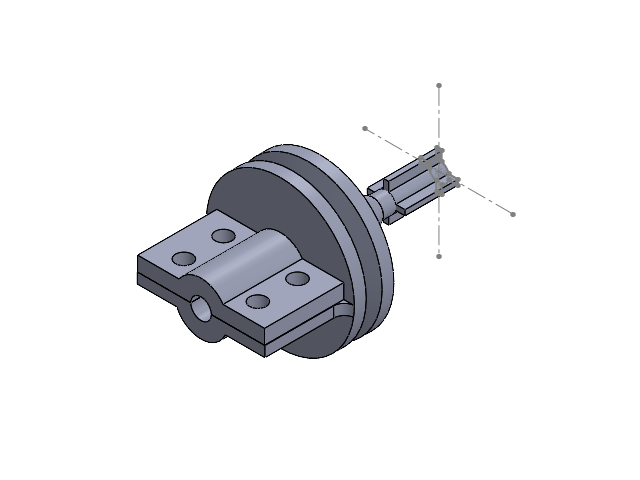
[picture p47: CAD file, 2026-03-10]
Electrical/Warmup Project/CAD/clamp_assembly.SLDASM
clamp
crazyshaftv1

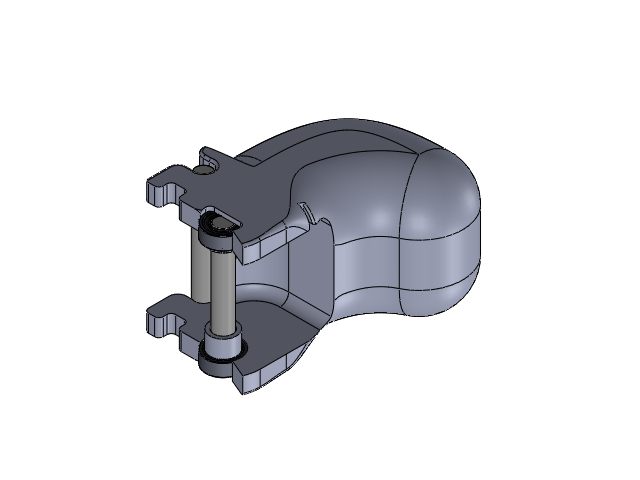
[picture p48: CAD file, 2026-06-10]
Mechanical/Assemblies/Link parts for simulation/pip_flexion.SLDASM
Fingertip Phalange_1
91585A465_18-8 Stainless Steel Dowel Pin_1 x 2
inner_ring_71 x 2
outer_ring_172 x 2
bearing_ball_65 x 18
sheild_67 x 4
metal_cage_56 x 2
_001_miniature_ball_bearing_inch x 2
Flexion Tendon Pulley Spacer_1
PIP Spacer_1

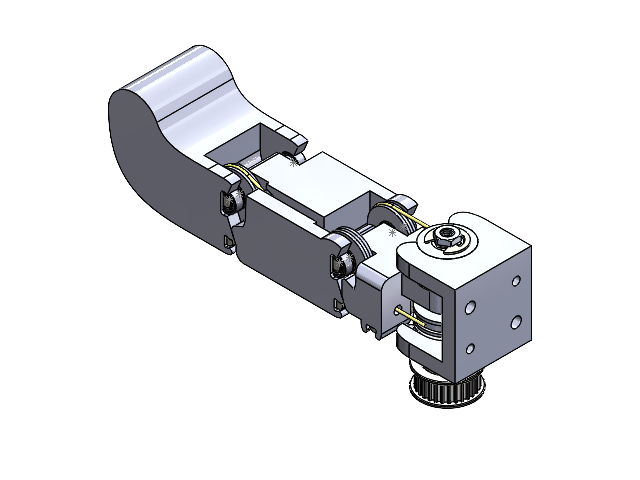
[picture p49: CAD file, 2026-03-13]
Mechanical/Assemblies/Link_Assembly_Final.SLDASM
FingerLink
FingerMCP
FingerBase
Flexion Tendon Pulley x 3
inner_ring_71 x 7
outer_ring_172 x 7
bearing_ball_65 x 63
sheild_67 x 14
metal_cage_56 x 7
_001_miniature_ball_bearing_inch x 7
17mmOD_Flanged x 4
Flexion Tendon Pulley Spacer x 3
91585A465_18-8 Stainless Steel Dowel Pin x 5
PIP Spacer
BearingMCPSpacer x 2
Fingertip Phalange
MCP Splay Free Spacer x 2
2806-0005-0004.step x 2
eBom-FreeParts.step
MCPBearingFlange x 2
Part1^Link_Assembly_Final
Part2^Link_Assembly_Final
97431A310_Side-Mount External Retaining Rings x 2

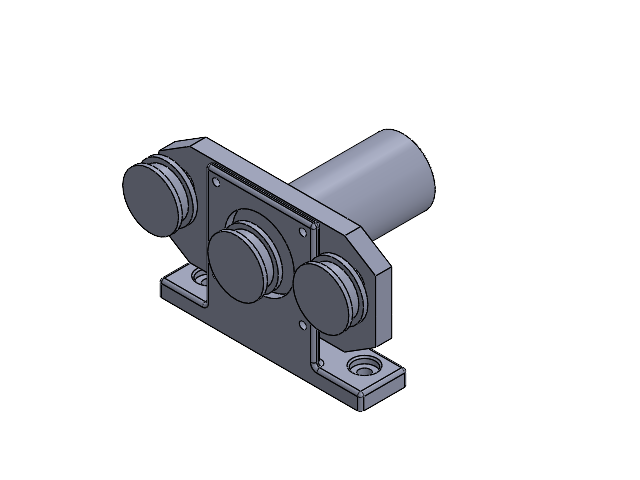
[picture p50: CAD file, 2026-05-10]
Mechanical/Load Cell Assembly/PIPTensionSensorAssembly.SLDASM
3_pulley_tension_load_cell
TensionMountRight

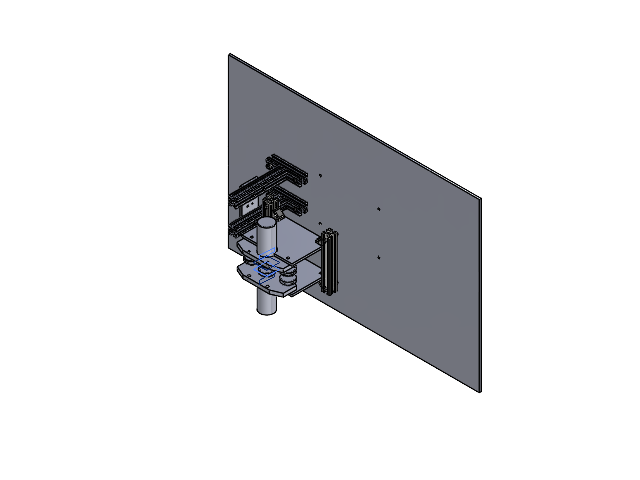
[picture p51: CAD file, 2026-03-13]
Mechanical/Assemblies/FullAssembly_v2.SLDASM
base_plate_full_assembly
80-20 _base_finger_supports x 2
80-20_vertical_finger_supports x 2
chuck_connector x 2
Plate_support_finger
97654A222_18-8 Stainless Steel Flanged Button Head Screw x 12
47065T553_T-Slotted Framing x 2
3_pulley_tension_load_cell x 2
LoadCellPlate x 2
47065T216_Corner Brace x 4
94168A112_Medium-Strength Steel Thin-Profile Hex Nut x 4

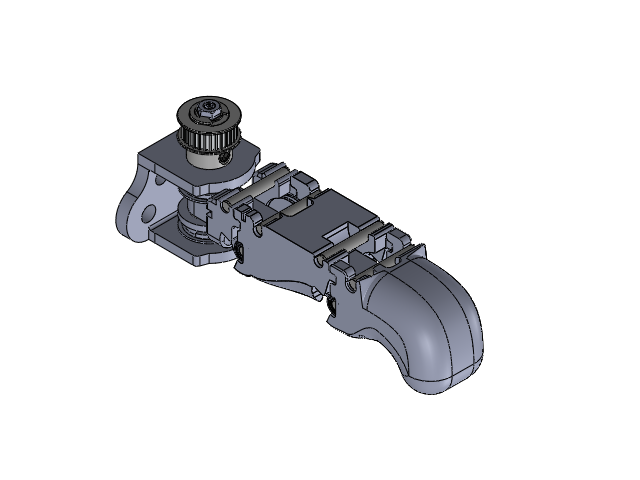
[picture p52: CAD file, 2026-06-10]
Mechanical/Assemblies/Link parts for simulation/Full assembly_visual.SLDASM
2806-0005-0004.step x 2
eBom-FreeParts.step
97431A310_Side-Mount External Retaining Rings_1 x 2
7804K145_Corrosion-Resistant 440C Stainless Steel Ball Bearing_1 x 6
FingerMCP_1
MCP Splay Wraparound Pulley_1 x 2
MCP Wraparound Shims_1 x 4
91585A465_18-8 Stainless Steel Dowel Pin_1 x 6
FingerLinkExperimental_1
inner_ring_71 x 6
outer_ring_172 x 6
bearing_ball_65 x 54
sheild_67 x 12
metal_cage_56 x 6
_001_miniature_ball_bearing_inch x 6
Flexion Tendon Pulley Spacer_1 x 3
Flexion Tendon Pulley_1 x 2
Fingertip Phalange_1
PIP Spacer_1
AngledFingerBaseNoSnapfit_1

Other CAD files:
Mechanical/Direct drive prototype/Assem1.SLDASM
Mechanical/Flexion Motor/Assem2.SLDASM
Mechanical/Assemblies/Link_Assembly_End.SLDASM
Mechanical/Direct drive prototype/Direct_drive1.SLDASM
Drake/minimalist finger objs/1516-4008-0560-Boss-Extrude2.obj
Drake/minimalist finger objs/17mmOD_Flanged.obj
Drake/minimalist finger objs/3422-4008-0030.obj
Drake/minimalist finger objs/3422-4008-0030parts.obj
Drake/minimalist finger objs/7804K145_CorrosionResistant440CStainlessSteelBallBearing.obj
Drake/minimalist finger objs/BearingMCPSpacer.obj
Drake/minimalist finger objs/FingerBase.obj
Drake/minimalist finger objs/FingerLink.obj
Drake/minimalist finger objs/FingerMCP.obj
Drake/minimalist finger objs/FingerShaft.obj
Drake/minimalist finger objs/FingertipPhalange.obj
Drake/minimalist finger objs/Flexion Tendon Pulley Spacer Shim.obj
Drake/minimalist finger objs/Flexion Tendon Pulley Spacer.obj
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

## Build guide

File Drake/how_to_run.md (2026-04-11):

# Minimalist Finger Model
This project runs a Drake-based finger model visualization on Linux.

## Setup Instructions

### 1. Install Drake and required dependencies
Make sure Drake and its dependencies are installed on your Linux system.  
You can also use an online platform that supports Drake if you prefer not to install it locally.

### 2. Download the required project folders
Download the following folders from the repository:

- `minimalist finger objs`
- `minimalist finger sdfs`

### 3. Update mesh paths inside the SDF files
Each `.sdf` file contains `<uri>` entries that point to the `.obj` mesh files.

Open every SDF file in the `minimalist finger sdfs` folder and update the paths inside each `<uri>` tag so they match the local path where your `minimalist finger objs` folder is stored.

For example, change:
<uri>old/path/to/file.obj</uri> to: <uri>/home/your_username/path_to_project/minimalist finger objs/file.obj</uri>

### 4. Run the python file
python3 finger_model.py

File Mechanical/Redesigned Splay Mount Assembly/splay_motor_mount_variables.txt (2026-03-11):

"testbed_height" = 91.50mm
"plate_thickness" = 6mm
"main_body_splay_length" = 48.5mm
"splay_shaft_length_no_wires" = 10mm
"splay_shaft_length_wires" = 6.5mm
"timing_pulley_offset" = 0mm
"effective_motor_length" = "timing_pulley_offset" + "splay_shaft_length_no_wires" + "main_body_splay_length"
"80_20_side" = 25.4mm
"80_20_length" = 152.4mm
"80_20_optic_mount_length" = "80_20_length" - 25.4mm
"optic_board_hole_size" = 6.35mm
"total_mounting_length" = "testbed_height" - "effective_motor_length" - "80_20_side"
"mounting_vertical_portion_height" = "total_mounting_length" - 2 * "plate_thickness"
"face_mount_width" = 15.25mm
"center_dist_to_face_mount_vertical_screws" = 5mm

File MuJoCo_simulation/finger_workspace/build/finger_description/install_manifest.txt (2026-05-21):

/mnt/d/RDS-repo/RDS-2026---Minimalist/MuJoCo_simulation/finger_workspace/install/finger_description/share/finger_description/urdf/Full assembly_visual_urdf_export.csv
/mnt/d/RDS-repo/RDS-2026---Minimalist/MuJoCo_simulation/finger_workspace/install/finger_description/share/finger_description/urdf/finger.urdf
/mnt/d/RDS-repo/RDS-2026---Minimalist/MuJoCo_simulation/finger_workspace/install/finger_description/share/finger_description/meshes/base_link.STL
/mnt/d/RDS-repo/RDS-2026---Minimalist/MuJoCo_simulation/finger_workspace/install/finger_description/share/finger_description/meshes/mcp_link.STL
/mnt/d/RDS-repo/RDS-2026---Minimalist/MuJoCo_simulation/finger_workspace/install/finger_description/share/finger_description/meshes/pip_link.STL
/mnt/d/RDS-repo/RDS-2026---Minimalist/MuJoCo_simulation/finger_workspace/install/finger_description/share/finger_description/meshes/splay_link.STL
/mnt/d/RDS-repo/RDS-2026---Minimalist/MuJoCo_simulation/finger_workspace/install/finger_description/share/finger_description/launch/display.launch
/mnt/d/RDS-repo/RDS-2026---Minimalist/MuJoCo_simulation/finger_workspace/install/finger_description/share/finger_description/launch/gazebo.launch
/mnt/d/RDS-repo/RDS-2026---Minimalist/MuJoCo_simulation/finger_workspace/install/finger_description/share/finger_description/config/joint_names_Full assembly_visual_urdf_export.yaml
/mnt/d/RDS-repo/RDS-2026---Minimalist/MuJoCo_simulation/finger_workspace/install/finger_description/share/ament_index/resource_index/package_run_dependencies/finger_description
/mnt/d/RDS-repo/RDS-2026---Minimalist/MuJoCo_simulation/finger_workspace/install/finger_description/share/ament_index/resource_index/parent_prefix_path/finger_description
/mnt/d/RDS-repo/RDS-2026---Minimalist/MuJoCo_simulation/finger_workspace/install/finger_description/share/finger_description/environment/ament_prefix_path.sh
/mnt/d/RDS-repo/RDS-2026---Minimalist/MuJoCo_simulation/finger_workspace/install/finger_description/share/finger_description/environment/ament_prefix_path.dsv
/mnt/d/RDS-repo/RDS-2026---Minimalist/MuJoCo_simulation/finger_workspace/install/finger_description/share/finger_description/environment/path.sh
/mnt/d/RDS-repo/RDS-2026---Minimalist/MuJoCo_simulation/finger_workspace/install/finger_description/share/finger_description/environment/path.dsv
/mnt/d/RDS-repo/RDS-2026---Minimalist/MuJoCo_simulation/finger_workspace/install/finger_description/share/finger_description/local_setup.bash
/mnt/d/RDS-repo/RDS-2026---Minimalist/MuJoCo_simulation/finger_workspace/install/finger_description/share/finger_description/local_setup.sh
/mnt/d/RDS-repo/RDS-2026---Minimalist/MuJoCo_simulation/finger_workspace/install/finger_description/share/finger_description/local_setup.zsh
/mnt/d/RDS-repo/RDS-2026---Minimalist/MuJoCo_simulation/finger_workspace/install/finger_description/share/finger_description/local_setup.dsv
/mnt/d/RDS-repo/RDS-2026---Minimalist/MuJoCo_simulation/finger_workspace/install/finger_description/share/finger_description/package.dsv
/mnt/d/RDS-repo/RDS-2026---Minimalist/MuJoCo_simulation/finger_workspace/install/finger_description/share/ament_index/resource_index/packages/finger_description
/mnt/d/RDS-repo/RDS-2026---Minimalist/MuJoCo_simulation/finger_workspace/install/finger_description/share/finger_description/cmake/finger_descriptionConfig.cmake
/mnt/d/RDS-repo/RDS-2026---Minimalist/MuJoCo_simulation/finger_workspace/install/finger_description/share/finger_description/cmake/finger_descriptionConfig-version.cmake
/mnt/d/RDS-repo/RDS-2026---Minimalist/MuJoCo_simulation/finger_workspace/install/finger_description/share/finger_description/package.xml

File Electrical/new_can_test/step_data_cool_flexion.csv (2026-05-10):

t_ms | target1 | pos1 | target2 | pos2 | target3 | pos3 | targetm1 | am1 | targetm2 | am2 | targetm3 | am3
139959.0 | 0.0 | -0.0 | 0.0 | 0.0 | 1.2 | 1.19 | 0.42 | 0.42 | 0.89 | 0.89 | 2.74 | 2.73
140059.0 | 0.0 | -0.0 | 1.2 | 0.33 | 0.0 | 1.1 | 0.42 | 0.42 | -1.03 | 0.37 | -1.1 | 2.06
140159.0 | 0.0 | -0.0 | 1.2 | 0.82 | 0.0 | 0.55 | 0.42 | 0.42 | -1.03 | -0.42 | -1.1 | 0.4
140259.0 | 0.0 | -0.0 | 1.2 | 1.03 | 0.0 | 0.24 | 0.42 | 0.42 | -1.03 | -0.76 | -1.1 | -0.44
140359.0 | 0.0 | -0.0 | 1.2 | 1.13 | 0.0 | 0.1 | 0.42 | 0.42 | -1.03 | -0.91 | -1.1 | -0.81
140459.0 | 0.0 | -0.0 | 1.2 | 1.17 | 0.0 | 0.04 | 0.42 | 0.42 | -1.03 | -0.97 | -1.1 | -0.97
140559.0 | 0.0 | -0.0 | 1.2 | 1.18 | 0.0 | 0.02 | 0.42 | 0.42 | -1.03 | -1.0 | -1.1 | -1.04
140659.0 | 0.0 | -0.0 | 1.2 | 1.19 | 0.0 | 0.01 | 0.42 | 0.42 | -1.03 | -1.02 | -1.1 | -1.07
140759.0 | 0.0 | -0.0 | 1.2 | 1.2 | 0.0 | 0.0 | 0.42 | 0.42 | -1.03 | -1.02 | -1.1 | -1.08
140859.0 | 0.0 | -0.0 | 1.2 | 1.2 | 0.0 | -0.0 | 0.42 | 0.42 | -1.03 | -1.02 | -1.1 | -1.09
140959.0 | 0.0 | -0.0 | 1.2 | 1.2 | 0.0 | -0.0 | 0.42 | 0.42 | -1.03 | -1.02 | -1.1 | -1.09
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

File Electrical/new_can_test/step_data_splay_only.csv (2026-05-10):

t_ms | target1 | pos1 | target2 | pos2 | target3 | pos3 | targetm1 | am1 | targetm2 | am2 | targetm3 | am3
135748.0 | 0.3 | 0.3 | 0.0 | -0.0 | 0.0 | -0.0 | 0.96 | 0.96 | -0.98 | -0.98 | 1.92 | 1.93
135848.0 | 0.3 | 0.3 | 0.0 | -0.0 | 0.0 | -0.0 | 0.96 | 0.96 | -0.98 | -0.98 | 1.92 | 1.93
135948.0 | 0.3 | 0.3 | 0.0 | -0.0 | 0.0 | -0.0 | 0.96 | 0.96 | -0.98 | -0.98 | 1.92 | 1.93
136048.0 | -0.3 | 0.15 | 0.0 | -0.0 | 0.0 | -0.0 | -0.19 | 0.67 | 0.22 | -0.68 | 3.12 | 2.23
136148.0 | -0.3 | -0.13 | 0.0 | -0.0 | 0.0 | -0.0 | -0.19 | 0.13 | 0.22 | -0.12 | 3.12 | 2.79
136248.0 | -0.3 | -0.24 | 0.0 | 0.0 | 0.0 | -0.0 | -0.19 | -0.07 | 0.22 | 0.09 | 3.12 | 2.99
136348.0 | -0.3 | -0.28 | 0.0 | 0.0 | 0.0 | -0.0 | -0.19 | -0.14 | 0.22 | 0.17 | 3.12 | 3.07
136448.0 | -0.3 | -0.29 | 0.0 | -0.0 | 0.0 | -0.0 | -0.19 | -0.17 | 0.22 | 0.2 | 3.12 | 3.1
136548.0 | -0.3 | -0.29 | 0.0 | -0.0 | 0.0 | -0.0 | -0.19 | -0.17 | 0.22 | 0.21 | 3.12 | 3.11
136648.0 | -0.3 | -0.3 | 0.0 | -0.0 | 0.0 | -0.0 | -0.19 | -0.18 | 0.22 | 0.21 | 3.12 | 3.11
136748.0 | -0.3 | -0.3 | 0.0 | 0.0 | 0.0 | -0.0 | -0.19 | -0.18 | 0.22 | 0.21 | 3.12 | 3.11
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

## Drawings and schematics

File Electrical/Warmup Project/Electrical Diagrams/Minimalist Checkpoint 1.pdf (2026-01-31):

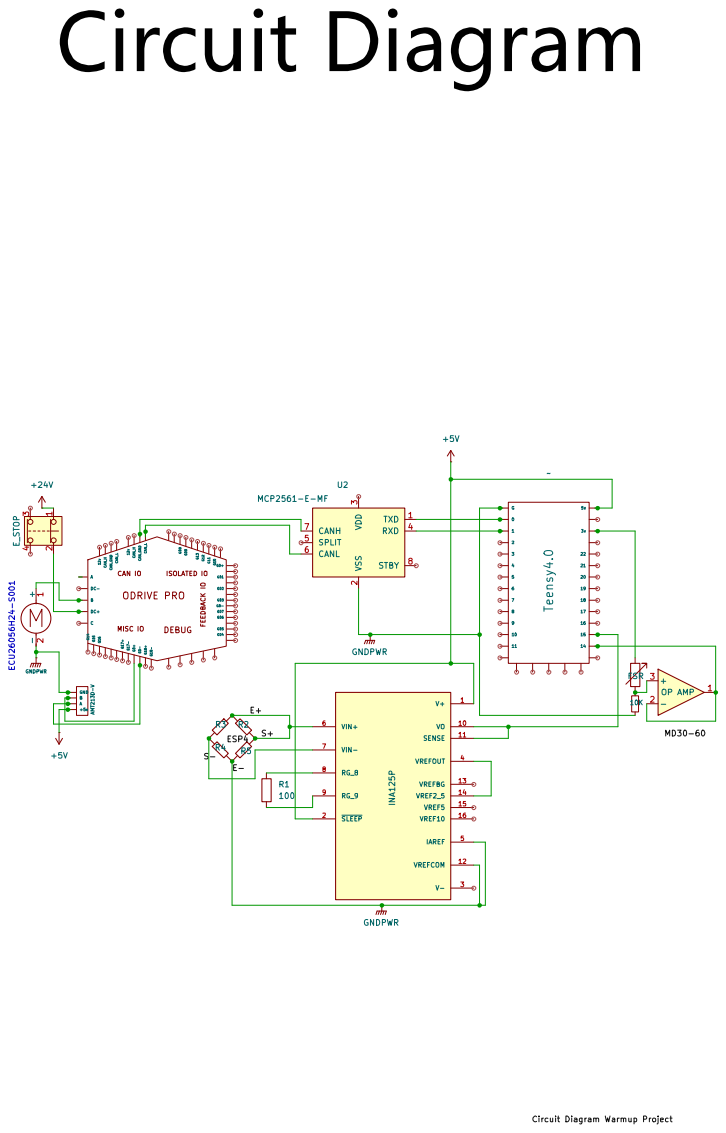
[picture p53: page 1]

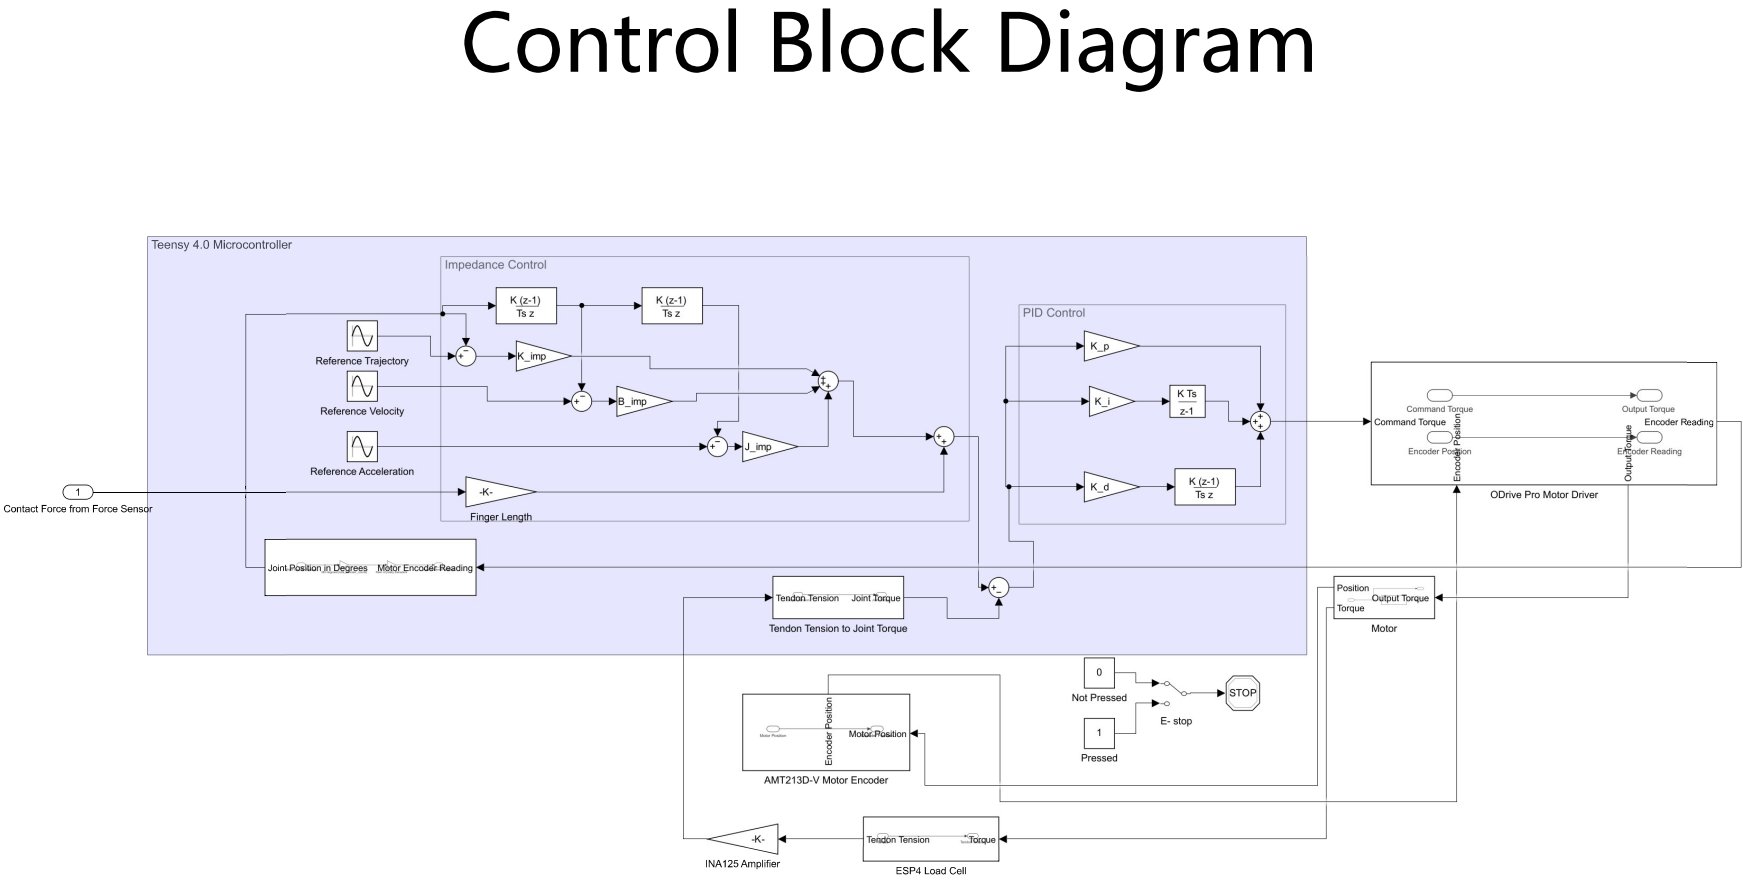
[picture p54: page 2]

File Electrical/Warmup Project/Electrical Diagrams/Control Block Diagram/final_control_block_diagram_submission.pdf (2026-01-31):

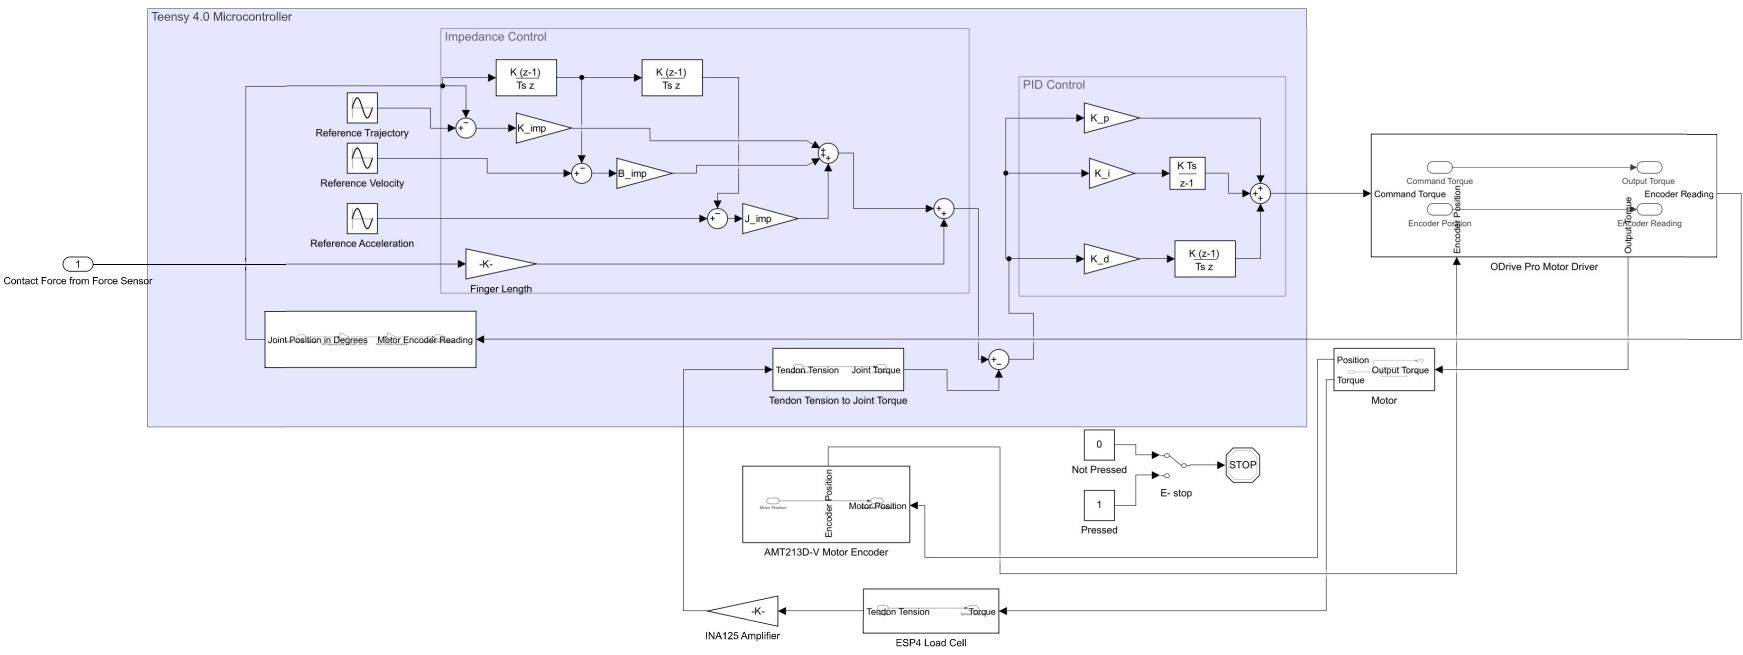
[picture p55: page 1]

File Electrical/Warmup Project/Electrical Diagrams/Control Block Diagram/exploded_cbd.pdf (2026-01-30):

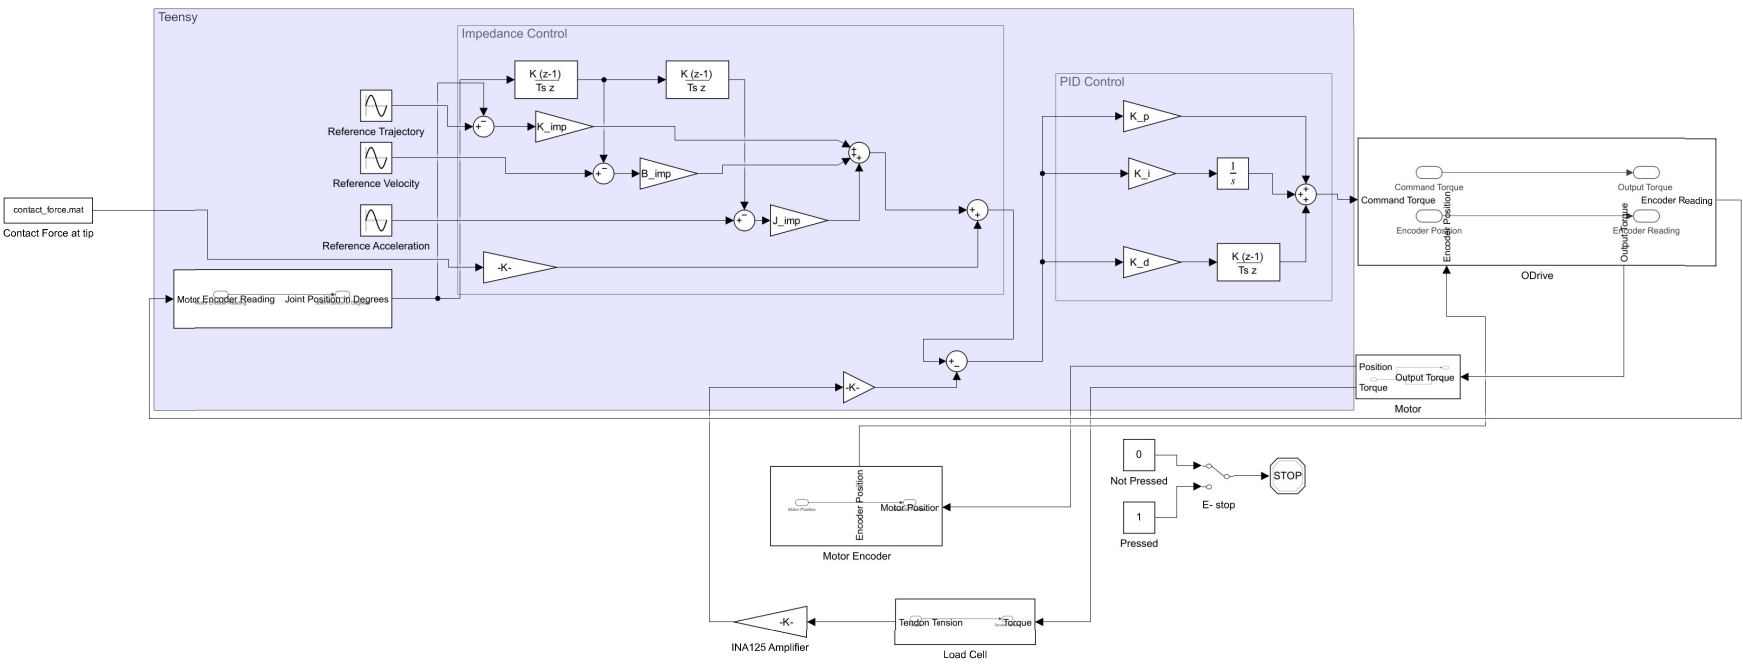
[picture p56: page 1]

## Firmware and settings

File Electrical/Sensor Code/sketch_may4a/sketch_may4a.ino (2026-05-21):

/*
 * ADS1220 Load Cell Calibration - Teensy 4.1, SPI1
 * Wiring: E+ -> 3.3V (and AIN0/REFP1), E- -> GND (and AIN3/REFN1),
 *         S+ -> AIN1, S- -> AIN2
 * Ratiometric reference uses REFP1/REFN1 (= AIN0/AIN3 pins)
 *
 * Workflow:
 *   1. Upload, open serial monitor at 115200, line ending "Newline"
 *   2. With NO load applied: type 't' to tare
 *   3. Apply known load, type 'c <value>' (e.g. 'c 5.0')
 *   4. Repeat with different loads (3+ points recommended)
 *   5. Type 'f' to fit and print calibration constants
 *   6. Type 's' to stream calibrated readings
 *   7. Copy printed constants into your main sketch
 *
 * Commands:
 *   t          Tare (zero with no load)
 *   c <value>  Record calibration point at known value
 *   l          List calibration points
 *   x          Clear all calibration points
 *   f          Fit and print constants
 *   s          Toggle streaming
 *   r          Single raw reading
 *   ?          Help
 */

#include <SPI.h>

// ---------- Pin and SPI config ----------
constexpr uint8_t PIN_CS   = 38;
constexpr uint8_t PIN_MOSI = 26;
constexpr uint8_t PIN_MISO = 39;
constexpr uint8_t PIN_SCK  = 27;

SPISettings adsSPI(100'000, MSBFIRST, SPI_MODE1);

// ---------- ADS1220 commands ----------
constexpr uint8_t CMD_RESET = 0x06;
constexpr uint8_t CMD_START = 0x08;
constexpr uint8_t CMD_WREG  = 0x40;
constexpr uint8_t CMD_RREG  = 0x20;

// ---------- Calibration state ----------
constexpr uint8_t MAX_CAL_POINTS = 10;

struct CalPoint {
  float knownValue;
  float rawAvg;
};

CalPoint calPoints[MAX_CAL_POINTS];
uint8_t numCalPoints = 0;

float zeroOffset    = 0.0f;
float countsPerUnit = 1.0f;
const char* unitLabel = "units";  // change to "kg", "N", "lb"

bool streaming = false;
uint32_t lastStreamMs = 0;

// ---------- Low-level helpers ----------
inline void csLow()  { digitalWriteFast(PIN_CS, LOW);  delayMicroseconds(5); }
inline void csHigh() { delayMicroseconds(5); digitalWriteFast(PIN_CS, HIGH); }

void sendCmd(uint8_t cmd) {
  SPI1.beginTransaction(adsSPI);
  csLow();
  SPI1.transfer(cmd);
  csHigh();
  SPI1.endTransaction();
  delayMicroseconds(20);
}

void writeReg(uint8_t reg, uint8_t val) {
  SPI1.beginTransaction(adsSPI);
  csLow();
  SPI1.transfer(CMD_WREG | (reg << 2));
  SPI1.transfer(val);
  csHigh();
  SPI1.endTransaction();
  delayMicroseconds(20);
}

uint8_t readReg(uint8_t reg) {
  SPI1.beginTransaction(adsSPI);
  csLow();
  SPI1.transfer(CMD_RREG | (reg << 2));
  uint8_t v = SPI1.transfer(0x00);
  csHigh();
  SPI1.endTransaction();
  delayMicroseconds(20);
  return v;
}

int32_t readData() {
  SPI1.beginTransaction(adsSPI);
  csLow();
  uint8_t b2 = SPI1.transfer(0x00);
  uint8_t b1 = SPI1.transfer(0x00);
  uint8_t b0 = SPI1.transfer(0x00);
  csHigh();
  SPI1.endTransaction();
  int32_t r = ((int32_t)b2 << 16) | ((int32_t)b1 << 8) | b0;
  if (r & 0x800000) r |= 0xFF000000;
  return r;
}

// ---------- ADC setup for load cell ----------
void adsInit() {
  sendCmd(CMD_RESET);
  delay(50);

  // REG0: MUX=0101 (AIN1/AIN2 differential), GAIN=111 (128x), PGA enabled -> 0x5E
  writeReg(0x00, 0x5E);
  // REG1: 20 SPS, normal mode, continuous conversion -> 0x04
  writeReg(0x01, 0x04);
  // REG2: VREF=10 (external REFP1/REFN1 = AIN0/AIN3 pins), 50/60Hz reject -> 0xB0
  writeReg(0x02, 0xB0);
  // REG3: defaults
  writeReg(0x03, 0x00);

  // Verify
  Serial.println("Register settings:");
  for (uint8_t i = 0; i < 4; i++) {
    Serial.printf("  REG%u = 0x%02X\n", i, readReg(i));
  }

  sendCmd(CMD_START);
  delay(100);
}

// ---------- Sample averaging ----------
float averageRaw(uint16_t samples) {
  int64_t sum = 0;
  for (uint16_t i = 0; i < samples; i++) {
    delay(55);  // pace at ~20 SPS
    sum += readData();
  }
  return (float)sum / samples;
}

// ---------- Linear fit (least squares) ----------
bool fitCalibration() {
  if (numCalPoints < 1) {
    Serial.println("Need at least 1 calibration point (plus tare).");
    return false;
  }

  // Include tare point and all calibration points
  float xs[MAX_CAL_POINTS + 1];
  float ys[MAX_CAL_POINTS + 1];
  uint8_t n = 0;

  xs[n] = 0.0f;
  ys[n] = zeroOffset;
  n++;

  for (uint8_t i = 0; i < numCalPoints; i++) {
    xs[n] = calPoints[i].knownValue;
    ys[n] = calPoints[i].rawAvg;
    n++;
  }

  float sumX = 0, sumY = 0, sumXY = 0, sumX2 = 0;
  for (uint8_t i = 0; i < n; i++) {
    sumX  += xs[i];
    sumY  += ys[i];
    sumXY += xs[i] * ys[i];
    sumX2 += xs[i] * xs[i];
  }
  float denom = n * sumX2 - sumX * sumX;
  if (fabsf(denom) < 1e-9f) {
    Serial.println("Fit failed: degenerate data.");
    return false;
  }
  float slope     = (n * sumXY - sumX * sumY) / denom;
  float intercept = (sumY - slope * sumX) / n;

  countsPerUnit = slope;
  zeroOffset    = intercept;

  // R^2
  float meanY = sumY / n;
  float ssTot = 0, ssRes = 0;
  for (uint8_t i = 0; i < n; i++) {
    float yPred = slope * xs[i] + intercept;
    ssRes += (ys[i] - yPred) * (ys[i] - yPred);
    ssTot += (ys[i] - meanY)  * (ys[i] - meanY);
  }
  float r2 = (ssTot > 0.0f) ? (1.0f - ssRes / ssTot) : 1.0f;

  Serial.println();
  Serial.println("=== CALIBRATION RESULT ===");
  Serial.printf("  Points used:    %u\n", n);
  Serial.printf("  Zero offset:    %.2f counts\n", zeroOffset);
  Serial.printf("  Counts per %s:  %.4f\n", unitLabel, countsPerUnit);
  Serial.printf("  R^2 fit:        %.6f\n", r2);
  Serial.println();
  Serial.println("Copy these into your main sketch:");
  Serial.printf("  float zeroOffset    = %.4ff;\n", zeroOffset);
  Serial.printf("  float countsPerUnit = %.4ff;\n", countsPerUnit);
  Serial.println();
  Serial.printf("Conversion: %s = (raw - zeroOffset) / countsPerUnit;\n", unitLabel);
  Serial.println("==========================\n");
  return true;
}

// ---------- Command handlers ----------
void cmdTare() {
  Serial.println("Taring... ensure NO load is applied.");
  Serial.println("Sampling 64 readings...");
  zeroOffset = averageRaw(64);
  Serial.printf("Zero offset: %.2f counts.\n", zeroOffset);
}

void cmdAddPoint(float knownValue) {
  if (numCalPoints >= MAX_CAL_POINTS) {
    Serial.println("Buffer full. Use 'x' or 'f'.");
    return;
  }
  Serial.printf("Recording point at %.4f %s.\n", knownValue, unitLabel);
  Serial.println("Sampling 64 readings...");
  float avg = averageRaw(64);
  calPoints[numCalPoints].knownValue = knownValue;
  calPoints[numCalPoints].rawAvg     = avg;
  numCalPoints++;
  Serial.printf("Point %u: known=%.4f %s, raw=%.2f (delta=%.2f)\n",
                numCalPoints, knownValue, unitLabel, avg, avg - zeroOffset);
}

void cmdListPoints() {
  Serial.println("\n=== Calibration points ===");
  Serial.printf("Tare:  known=0.0000 %s, raw=%.2f\n", unitLabel, zeroOffset);
  for (uint8_t i = 0; i < numCalPoints; i++) {
    Serial.printf("Pt %u:  known=%.4f %s, raw=%.2f (delta=%.2f)\n",
                  i + 1, calPoints[i].knownValue, unitLabel,
                  calPoints[i].rawAvg, calPoints[i].rawAvg - zeroOffset);
  }
  Serial.println("==========================\n");
}

void cmdClear() {
  numCalPoints = 0;
  zeroOffset = 0.0f;
  Serial.println("Cleared. Run 't' to tare.");
}

void cmdHelp() {
  Serial.println("\n=== Commands ===");
  Serial.println("  t          Tare (zero with no load)");
  Serial.println("  c <value>  Record calibration point");
  Serial.println("  l          List points");
  Serial.println("  x          Clear all");
  Serial.println("  f          Fit and print constants");
  Serial.println("  s          Toggle streaming");
  Serial.println("  r          Single raw reading");
  Serial.println("  ?          Help");
  Serial.println("================\n");
}

// ---------- Serial command parser ----------
void processCommand(const String& line) {
  String s = line;
  s.trim();
  if (s.length() == 0) return;

  char cmd = s.charAt(0);
  String arg = (s.length() > 1) ? s.substring(1) : String("");
  arg.trim();

  switch (cmd) {
    case 't': cmdTare(); break;
    case 'c':
      if (arg.length() == 0) Serial.println("Usage: c <value>");
      else cmdAddPoint(arg.toFloat());
      break;
    case 'l': cmdListPoints(); break;
    case 'x': cmdClear(); break;
    case 'f': fitCalibration(); break;
    case 's':
      streaming = !streaming;
      Serial.println(streaming ? "Streaming ON." : "Streaming OFF.");
      break;
    case 'r': {
      int32_t r = readData();
      Serial.printf("raw = %ld\n", r);
      break;
    }
    case '?': case 'h': cmdHelp(); break;
    default:
      Serial.printf("Unknown command: '%c'. Type ? for help.\n", cmd);
      break;
  }
}

// ---------- Setup and loop ----------
void setup() {
  Serial.begin(115200);
  while (!Serial && millis() < 3000) {}
  delay(200);

  pinMode(PIN_CS, OUTPUT);
  digitalWriteFast(PIN_CS, HIGH);

  SPI1.setMOSI(PIN_MOSI);
  SPI1.setMISO(PIN_MISO);
  SPI1.setSCK(PIN_SCK);
  SPI1.begin();
  delay(50);

  adsInit();

  Serial.println();
  Serial.println("==========================================");
  Serial.println("  ADS1220 Load Cell Calibration");
  Serial.println("  Inputs: AIN1/AIN2, Ref: REFP1/REFN1");
  Serial.println("==========================================");
  Serial.printf("  Unit: %s (edit 'unitLabel' to change)\n", unitLabel);
  cmdHelp();
}

void loop() {
  static String inputBuf;
  while (Serial.available()) {
    char c = Serial.read();
    if (c == '\n' || c == '\r') {
      if (inputBuf.length() > 0) {
        processCommand(inputBuf);
        inputBuf = "";
      }
    } else {
      inputBuf += c;
    }
  }

  if (streaming && (millis() - lastStreamMs >= 100)) {
    lastStreamMs = millis();
    int32_t raw = readData();
    float value = (raw - zeroOffset) / countsPerUnit;
    Serial.printf("raw=%ld  %.4f %s\n", raw, value, unitLabel);
  }
}

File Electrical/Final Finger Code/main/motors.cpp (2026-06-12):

#include "motors.h"

bool initial_loop_mcp = true;
bool initial_loop_dip = true;
float prev_error_mcp;
float i_error_mcp = 0;
float prev_error_dip;
float i_error_dip = 0;

// CAN COMMUNICATION
float float_to_uint(float x, float x_min, float x_max, int bits) {
    float span = x_max - x_min;
    return (int)((x - x_min) * ((float)((1 << bits) - 1)) / span);
}

void comm_can_transmit_sid(uint32_t id, const uint8_t *data, uint8_t len, uint8_t flag_extended){
  if (len>8){
    len = 8;
  } 

  CAN_message_t msg;
  msg.id = id;
  msg.flags.extended = flag_extended;
  msg.len = len;

  for (int i=0; i<len; i++){
    msg.buf[i] = data[i];
  }

  can_3.write(msg);
}

// ====== Process Incoming CAN Messages ======
void process_can_message(motor_axis *axis, const CAN_message_t &rxMsg) {
    if ((rxMsg.id & 0xFF) == axis->controller_id) {
        axis->motor_pos = (rxMsg.buf[0] << 8) | rxMsg.buf[1];
        axis->motor_spd = (rxMsg.buf[2] << 8) | rxMsg.buf[3];
        axis->motor_cur = (rxMsg.buf[4] << 8) | rxMsg.buf[5];
        axis->motor_temp = rxMsg.buf[6];
        axis->motor_error = rxMsg.buf[7];
    }
}

// ====== Debug Function to Print Motor Data ======
void debug_motor(motor_axis *axis) {
    Serial.print("Motor ID: "); Serial.println(axis->controller_id);
    Serial.print("Position: "); Serial.println(axis->motor_pos);
    Serial.print("Speed: "); Serial.println(axis->motor_spd);
    Serial.print("Current: "); Serial.println(axis->motor_cur);
    Serial.print("Temperature: "); Serial.println(axis->motor_temp);
    Serial.print("Error: "); Serial.println(axis->motor_error);
}

//All numbers in the packet are converted to floating point by the following function. 
float uint_to_float(int x_int, float x_min, float x_max, int bits){
  /// converts unsigned int to float, given range and number of bits ///
  float span = x_max - x_min;
  float offset = x_min;
  return ((float)x_int)*span/((float)((1<<bits)-1)) + offset;
}

void get_encoder_values(motor_axis *axis) {
  uint8_t enc_bytes[8] = {0xFF, 0xFF, 0xFF, 0xFF, 0xFF, 0xFF, 0xFF, 0xFC};
  comm_can_transmit_sid(axis->controller_id, enc_bytes, 8, 0);
}

void unpack_reply(CAN_message_t *RxMessage, int id_desired){
  /// unpack ints from can buffer ///
  
  id = RxMessage->buf[0]; //driver id number
  p_int = ( RxMessage->buf[1]<<8) | RxMessage->buf[2]; // motor position buf
  v_int = ( RxMessage->buf[3]<<4)|( RxMessage->buf[4]>>4); //motor speed value
  i_int = (( RxMessage->buf[4]&0xF)<<8)| RxMessage->buf[5]; //motor torque value
  T_int = RxMessage->buf[6];

  /// convert ints to floats ///
  //float p = uint_to_float(p_int, P_MIN, P_MAX, 16);
  //float v = uint_to_float(v_int, V_MIN, V_MAX, 12);
  //float i = uint_to_float(i_int, -T_MAX, T_MAX, 12);
  //float T =T_int;

  if(id == id_desired){
    position = uint_to_float(p_int, P_MIN, P_MAX, 16);
    speed = uint_to_float(v_int, V_MIN, V_MAX, 12);
    torque = uint_to_float(i_int, -T_MAX, T_MAX, 12);
    Temperature = T_int-40; //temperature range-40~215
  }
}


float get_torque(CAN_message_t *RxMessage){
  /// unpack ints from can buffer ///
  
    id = RxMessage->buf[0]; //driver id number
    i_int = (( RxMessage->buf[4]&0xF)<<8)| RxMessage->buf[5]; //motor torque value
    float torque = uint_to_float(i_int, -T_MAX, T_MAX, 12);
    return torque;
}


float position;
float speed ;
float torque ;
float Temperature ;
int id;
int p_int;
int v_int;
int i_int;
float T_int;

void print_data(CAN_message_t rxMsg, int motorid){
    unpack_reply(&rxMsg, motorid);
    Serial.print("Id =");
    Serial.print(id);

    Serial.print("  Position = ");
    Serial.print(position);

    Serial.print("  speed = ");
    Serial.print(speed);

    Serial.print("  torque = ");
    Serial.print(torque);

    Serial.print("  Temperature = ");
    Serial.print(Temperature);
}

// ================================================ MOTORS ===============================================================
void enter_MIT_control_mode(){
  uint8_t control_mode_bytes[8] = {0xFF, 0xFF, 0xFF, 0xFF, 0xFF, 0xFF, 0xFF, 0XFC};
  comm_can_transmit_sid(MOTOR1_ID, control_mode_bytes, 8, 0);
  delay(100);
  comm_can_transmit_sid(MOTOR2_ID, control_mode_bytes, 8, 0);
  delay(100);
  comm_can_transmit_sid(MOTOR3_ID, control_mode_bytes, 8,0);

}

void motor_enter_MIT_control_mode(motor_axis *axis) {
    uint8_t bytes[8] = {0xFF, 0xFF, 0xFF, 0xFF, 0xFF, 0xFF, 0xFF, 0xFC};
    comm_can_transmit_sid(axis->controller_id, bytes, 8,0);
}

void exit_MIT_control_mode() {
    uint8_t bytes[8] = {0xFF, 0xFF, 0xFF, 0xFF, 0xFF, 0xFF, 0xFF, 0xFD};
    comm_can_transmit_sid(MOTOR1_ID, bytes, 8,0);
    delay(100);
    comm_can_transmit_sid(MOTOR2_ID, bytes, 8,0);
    delay(100);
    comm_can_transmit_sid(MOTOR3_ID, bytes, 8,0);
}

// ====== Motor Initialization ======
void setup_motor(motor_axis *axis, uint8_t id, int dir) {
    axis->controller_id = id;
    axis->motor_dir = dir;
}

void set_position(motor_axis *axis, float pos_rad, float kp, float kd) {
    // Clamp inputs to valid ranges
    pos_rad = constrain(pos_rad, P_MIN, P_MAX);
    kp      = constrain(kp, 0.0f, 500.0f);
    kd      = constrain(kd, 0.0f, 5.0f);

    if (axis->controller_id == MOTOR3_ID) {
        kp = kp/MOTOR3_LOWER;
        kd = kd/MOTOR3_LOWER;
    }
    // Convert to 16/12-bit unsigned ints
    uint16_t pos_int = float_to_uint(pos_rad, P_MIN, P_MAX, 16);
    uint16_t vel_int = float_to_uint(0.0f,    V_MIN, V_MAX, 12);  // zero velocity
    uint16_t kp_int  = float_to_uint(kp,      0.0f,  500.0f, 12);
    uint16_t kd_int  = float_to_uint(kd,      0.0f,  5.0f,   12);
    uint16_t tor_int = float_to_uint(0.0f,    T_MIN, T_MAX,  12);  // zero feedforward torque

    // Pack into 8 bytes — AK-series MIT mode format
    uint8_t bytes[8];
    bytes[0] = pos_int >> 8;
    bytes[1] = pos_int & 0xFF;
    bytes[2] = vel_int >> 4;
    bytes[3] = ((vel_int & 0xF) << 4) | (kp_int >> 8);
    bytes[4] = kp_int & 0xFF;
    bytes[5] = kd_int >> 4;
    bytes[6] = ((kd_int & 0xF) << 4) | (tor_int >> 8);
    bytes[7] = tor_int & 0xFF;

    comm_can_transmit_sid(axis->controller_id, bytes, 8, 0);
}
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

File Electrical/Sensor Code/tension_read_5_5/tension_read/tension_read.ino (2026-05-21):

/*
 * Dual ADS1220 Tension Reader - Teensy 4.1
 *
 * Both ADCs share SPI1 (MOSI=26, MISO=39, SCK=27).
 * They are addressed by separate CS and DRDY lines:
 *   ADC0:  CS=10, DRDY=9
 *   ADC1:  CS=38, DRDY=29
 *
 * Both auto-tare at startup (no load applied), then stream paired readings.
 */

#include <SPI.h>

// ---------- Shared SPI1 bus pins ----------
constexpr uint8_t PIN_MOSI = 26;
constexpr uint8_t PIN_MISO = 39;
constexpr uint8_t PIN_SCK  = 27;

// ---------- Per-chip pins ----------
constexpr uint8_t PIN_CS0   = 10;
constexpr uint8_t PIN_DRDY0 = 9;

constexpr uint8_t PIN_CS1   = 38;
constexpr uint8_t PIN_DRDY1 = 29;

SPISettings adsSPI(100'000, MSBFIRST, SPI_MODE1);

// ---------- ADS1220 commands ----------
constexpr uint8_t CMD_RESET = 0x06;
constexpr uint8_t CMD_START = 0x08;
constexpr uint8_t CMD_WREG  = 0x40;

// ---------- Calibration ----------
const float countsPerUnit = 4157.5908f;
const char* unitLabel     = "N";

float zeroOffset0 = 0.0f;
float zeroOffset1 = 0.0f;

// ---------- DRDY timeout ----------
constexpr uint32_t DRDY_TIMEOUT_MS = 500;

// ---------- Per-channel state ----------
struct AdcChannel {
  SPIClass& bus;
  uint8_t   csPin;
  uint8_t   drdyPin;
  const char* name;
};

AdcChannel adc0 = { SPI1, PIN_CS0, PIN_DRDY0, "ADC0" };
AdcChannel adc1 = { SPI1, PIN_CS1, PIN_DRDY1, "ADC1" };

// ---------- Low-level SPI helpers (per channel) ----------
inline void csLow (const AdcChannel& a) { digitalWriteFast(a.csPin, LOW);  delayMicroseconds(5); }
inline void csHigh(const AdcChannel& a) { delayMicroseconds(5); digitalWriteFast(a.csPin, HIGH); }

void sendCmd(AdcChannel& a, uint8_t cmd) {
  a.bus.beginTransaction(adsSPI);
  csLow(a);
  a.bus.transfer(cmd);
  csHigh(a);
  a.bus.endTransaction();
  delayMicroseconds(20);
}

void writeReg(AdcChannel& a, uint8_t reg, uint8_t val) {
  a.bus.beginTransaction(adsSPI);
  csLow(a);
  a.bus.transfer(CMD_WREG | (reg << 2));
  a.bus.transfer(val);
  csHigh(a);
  a.bus.endTransaction();
  delayMicroseconds(20);
}

bool waitForDRDY(AdcChannel& a) {
  uint32_t t0 = millis();
  while (digitalRead(a.drdyPin) == HIGH) {
    if (millis() - t0 > DRDY_TIMEOUT_MS) {
      Serial.printf("WARNING: %s DRDY timeout.\n", a.name);
      return false;
    }
  }
  return true;
}

int32_t readData(AdcChannel& a) {
  if (!waitForDRDY(a)) return 0;
  a.bus.beginTransaction(adsSPI);
  csLow(a);
  uint8_t b2 = a.bus.transfer(0x00);
  uint8_t b1 = a.bus.transfer(0x00);
  uint8_t b0 = a.bus.transfer(0x00);
  csHigh(a);
  a.bus.endTransaction();
  int32_t r = ((int32_t)b2 << 16) | ((int32_t)b1 << 8) | b0;
  if (r & 0x800000) r |= 0xFF000000;
  return r;
}

float averageRaw(AdcChannel& a, uint16_t samples) {
  int64_t sum = 0;
  for (uint16_t i = 0; i < samples; i++) sum += readData(a);
  return (float)sum / (float)samples;
}

void adsInit(AdcChannel& a) {
  sendCmd(a, CMD_RESET);
  delay(50);
  writeReg(a, 0x00, 0x0E);  // AIN0/AIN1, gain=128, PGA on
  writeReg(a, 0x01, 0x04);  // 20 SPS, normal mode, continuous conversion
  writeReg(a, 0x02, 0x70);  // external ref REFP0/REFN0, 50/60Hz rejection
  writeReg(a, 0x03, 0x00);
  sendCmd(a, CMD_START);
  delay(100);
}

// ---------- Setup ----------
void setup() {
  Serial.begin(115200);
  while (!Serial && millis() < 3000) {}

  // Chip selects idle high BEFORE SPI1.begin() so neither chip latches stray clocks
  pinMode(PIN_CS0, OUTPUT); digitalWriteFast(PIN_CS0, HIGH);
  pinMode(PIN_CS1, OUTPUT); digitalWriteFast(PIN_CS1, HIGH);

  // DRDY inputs
  pinMode(PIN_DRDY0, INPUT);
  pinMode(PIN_DRDY1, INPUT);

  // Shared SPI1 bus
  SPI1.setMOSI(PIN_MOSI);
  SPI1.setMISO(PIN_MISO);
  SPI1.setSCK (PIN_SCK);
  SPI1.begin();

  delay(50);

  adsInit(adc0);
  adsInit(adc1);

  zeroOffset0 = averageRaw(adc0, 64);
  zeroOffset1 = averageRaw(adc1, 64);
  Serial.printf("Zero offsets:  ADC0=%.2f   ADC1=%.2f   counts\n",
                zeroOffset0, zeroOffset1);
}

// ---------- Loop ----------
void loop() {
  // Wait until both ADCs have a fresh sample, then print one paired line.
  if (digitalRead(PIN_DRDY0) == LOW && digitalRead(PIN_DRDY1) == LOW) {
    int32_t raw0 = readData(adc0);
    int32_t raw1 = readData(adc1);

    float val0 = (raw0 - zeroOffset0) / countsPerUnit;
    float val1 = (raw1 - zeroOffset1) / countsPerUnit;

    Serial.printf("ADC0 raw=%9ld  %.4f %s   |   ADC1 raw=%9ld  %.4f %s\n",
                  raw0, val0, unitLabel,
                  raw1, val1, unitLabel);
  }
}

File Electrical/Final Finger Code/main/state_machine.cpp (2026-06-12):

#include "state_machine.h"


float calibration_hardstops_motors[3] = {0, 0, 0};
bool first_time = true;
uint8_t flex_ext_print_cycle = 0;
float mcp_temp = 0;
float dip_temp = 0;
float splay_temp = 0;
float mcp_v = 0;
float dip_v = 0;
float splay_v = 0;
float mcp_i = 0;
float dip_i = 0;
float splay_i = 0;
bool header_printed = false;

volatile CONTROL_MODES cur_system_state = CALIBRATION;
CONTROL_MODES prev_system_state = STARTUP;

k dip_control_force = {0.009, 0, 0.001};
k dip_control_force_current = {0.006, 0, 0};


k mcp_control_force = {0.009, 0, 0.001};
k mcp_control_force_current = {0.006, 0, 0.001};

uint32_t initial_max_force_time = 0;
uint32_t lastCmd = 0;

FlexCAN_T4<CAN3, RX_SIZE_256, TX_SIZE_16> can_3;


motor_axis m1;
motor_axis m2;
motor_axis m3;

bool is_force(CONTROL_MODES cur_state) {
 return (cur_state == STEP_FORCE || cur_state == MAX_FORCE);
};

void switch_calibration() {
  cur_system_state = CALIBRATION;
}
void switch_step_position() {
  // Serial.println("step_pos");
  cur_system_state = STEP_POSITION;
}
void switch_lissajou_position() {
  cur_system_state = LISSAJOU_POSITION;
}
void switch_ellipse_position() {
  cur_system_state = ELLIPSE_POSITION;
}
void switch_zero_force() {
  cur_system_state = ZERO_FORCE;
}
void switch_step_force() {
  cur_system_state = STEP_FORCE;
}
void switch_max_force() {
  cur_system_state = MAX_FORCE;
}

void switch_flex_ext() {
  cur_system_state = FLEX_EXT;
}


void initial_universal_setup() {
  
  Serial.begin(115200);  
  if (!LOGGING) {Serial.println("Starting...");}
  delay(100);

  can_3.begin();
  can_3.setBaudRate(1000000);

  setup_motor(&m1, MOTOR1_ID, 1);
  setup_motor(&m2, MOTOR2_ID, 1);
  setup_motor(&m3, MOTOR3_ID, 1);  

  exit_MIT_control_mode();
  delay(1000);
  enter_MIT_control_mode();
    
  if (!LOGGING) {Serial.println("Entered MIT mode");}
  // set_position(&motor1, 2.5f, 8.0f, 0.5f);
  // set_position(&motor2, 2.5f, 8.0f, 0.5f);
  //  set_position(&motor3, 2*PI, 8.0f, 0.5f);  
  delay(100);
  cs_setup(PIN_CS_DIP,  PIN_DRDY_DIP);
  cs_setup(PIN_CS_MCP, PIN_DRDY_MCP);
  if (!LOGGING) {Serial.println("CS pins set up");}
  spi_setup();
  if (!LOGGING) {Serial.println("SPI setup");}
  adsInit(PIN_CS_DIP);
  adsInit(PIN_CS_MCP);
  if (!LOGGING) {Serial.println("ADS initialize");}
  pinMode(PIN_CALIBRATION, INPUT);
  pinMode(PIN_STEP_POSITION, INPUT);
  pinMode(PIN_LISSAJOU_POSITION, INPUT);
  pinMode(PIN_ELLIPSE_POSITION, INPUT);
  pinMode(PIN_ZERO_FORCE, INPUT);
  pinMode(PIN_STEP_FORCE, INPUT);
  pinMode(PIN_MAX_FORCE, INPUT);
  pinMode(PIN_FLEX_EXT, INPUT);

}

void calibration_setup() {
  if (!LOGGING) {Serial.println("Under zero torque for 5 seconds. Move pulleys accordingly.");}
  uint32_t start_zero_force = millis();
  while ((millis() - start_zero_force) < 5000) {
    set_torque(&m1, 0);
    set_torque(&m2, 0);
    set_torque(&m3, 0);
  }
  delay(1000);
  if (!LOGGING) {Serial.println("Now calibrating");}
  // position calibration
  full_calibration(calibration_hardstops_motors, &m1, &m2, &m3);
  if (!LOGGING) {Serial.print("Calibration offsets: ");
  Serial.println();}
  for (int i = 0; i < 3; i++) {
    if (!LOGGING) {Serial.print(calibration_hardstops_motors[i]);
    Serial.println();}
  }
  // tension sensor calibration
  uint32_t start_zero_time = millis();
  while (millis() - start_zero_time < 1000) {
    set_home_joint_position(&m1,&m2,&m3, calibration_hardstops_motors);
  zero_sensors();
}
}


void calibration_state() {
  // just stay in zero position after that
  set_home_joint_position(&m1,&m2,&m3, calibration_hardstops_motors);
  delay(10);
}

void position_setup() {}

void force_setup() {
  attachInterrupt(digitalPinToInterrupt(PIN_DRDY_DIP), isr_dip, FALLING);
  attachInterrupt(digitalPinToInterrupt(PIN_DRDY_MCP), isr_mcp, FALLING);
}

void flex_ext_setup() {
  detachInterrupt(digitalPinToInterrupt(PIN_CALIBRATION));
  detachInterrupt(digitalPinToInterrupt(PIN_STEP_POSITION));
  detachInterrupt(digitalPinToInterrupt(PIN_LISSAJOU_POSITION));
  detachInterrupt(digitalPinToInterrupt(PIN_ELLIPSE_POSITION));
  detachInterrupt(digitalPinToInterrupt(PIN_ZERO_FORCE));
  detachInterrupt(digitalPinToInterrupt(PIN_STEP_FORCE));
  detachInterrupt(digitalPinToInterrupt(PIN_MAX_FORCE));
  detachInterrupt(digitalPinToInterrupt(PIN_FLEX_EXT));
}

void flex_ext_state() {
  angles target_joint = generate_flex_ext_sinusoid();
        bool motor_on[3] = {true, true, true};
        // Send to motors
        // set_joint_position_w_automatic_ff_torque(&m1,&m2,&m3,
        //                 target_joint,
        //                 calibration_hardstops_motors,
        //                 25.0f, 3.0f, motor_on);
        set_joint_position(&m1,&m2,&m3,
                        target_joint,
                        calibration_hardstops_motors,
                        25.0f, 3.0f, motor_on);
    delay(10);
     CAN_message_t rxMsg;
     if (!header_printed) {
    Serial.println("time_ms,splay_temp,splay_vel,splay_torque,mcp_temp,mcp_vel,mcp_torque,dip_temp,dip_vel,dip_torque");
    header_printed = true;
}
  while (can_3.read(rxMsg)) {
      // Serial.print("GOT RESPONSE -->  ");
      int incoming_id = rxMsg.id;

      if (incoming_id == MOTOR1_ID){
        unpack_reply(&rxMsg, MOTOR1_ID); 
        splay_temp = Temperature;
        splay_v = speed;
        splay_i = torque;
        // print_data(rxMsg, MOTOR1_ID);
      }
      else if (incoming_id == MOTOR2_ID){
        unpack_reply(&rxMsg, MOTOR2_ID); 
        mcp_temp = Temperature;
        mcp_v = speed;
        mcp_i = torque;
        // print_data(rxMsg, MOTOR2_ID);
      }
      else if (incoming_id == MOTOR3_ID){
        unpack_reply(&rxMsg, MOTOR3_ID); 
        dip_temp = Temperature;
        dip_v = speed;
        dip_i = torque;
        // print_data(rxMsg, MOTOR3_ID);
      }     
  }
      // Serial.println();
    if (flex_ext_print_cycle >= 5) {
      flex_ext_print_cycle = 0;
      Serial.print(millis());
        Serial.print(",");
        Serial.print(splay_temp);
        Serial.print(",");
        Serial.print(splay_v);
        Serial.print(",");
        Serial.print(splay_i);
        Serial.print(",");
        Serial.print(mcp_temp);
        Serial.print(",");
        Serial.print(mcp_v);
        Serial.print(",");
        Serial.print(mcp_i);
        Serial.print(",");
        Serial.print(dip_temp);
        Serial.print(",");
        Serial.print(dip_v);
        Serial.print(",");
        Serial.println(dip_i);
    }
    else{
      flex_ext_print_cycle = flex_ext_print_cycle+1;
    }
}
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

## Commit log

2026-01-30 moved electrical stuff into electrical folder and created mechanical folder
    [1609-0610-0004.STEP, 6656K163_Ultra-Thin Ball Bearing.SLDPRT, Chuck.SLDPRT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]
2026-01-30 Added linkage diff CAD
    [4mm ID, 10 mm OD V-Groove Bearing.SLDPRT, 59935K12_Ball Joint Rod End.SLDPRT, 59935K14_Ball Joint Rod End.SLDPRT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]
2026-01-31 Ki Cad Files
    [Capstone.kicad_pcb, Capstone.kicad_sch]
2026-02-06 Direct drive 02/06
    [496650_ec-i40_50w_a.stp, 57545K644_Steel Worm.SLDPRT, Assem1.SLDASM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]
2026-02-08 Updates 2/7
    [Assem1.SLDASM, Direct_drive.SLDASM, Direct_drive1.SLDASM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]
2026-02-14 Motor attachment
    [motor_attach.STL]
2026-02-16 added motor shaft clamp
    [clamp.SLDPRT, clamp.STL, clamp_assembly.SLDASM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]
2026-02-16 updated clamp assembly and clamp to ensure that the tolerances where right
    [clamp.SLDPRT, clampv2.STL, crazyshaftv2.SLDPRT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]
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2026-02-26 a lot of stuff lol
    [1609-0610-0004.STEP, 4mm ID, 10 mm OD V-Groove Bearing.SLDPRT, 59935K12_Ball Joint Rod End.SLDPRT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]
2026-03-03 On axis tendon routing finger link CAD draft
    [7804K1_Stainless Steel Ball Bearing.SLDPRT, FingerLink.SLDPRT, FingerShaft.SLDPRT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]
2026-03-05 Last iteration with vgrooves in center
    [FingerLink.SLDPRT, Link_Assembly_Final.SLDASM]
2026-03-05 Printed version 1
    [FingerLink.SLDPRT, Link_Assembly_Final.SLDASM]
2026-03-05 Created MCP
    [1277N778_Corrosion-Resistant Timing Belt Pulley.SLDPRT, 3563N14_XL Series Lightweight Timing Belt Pulley.SLDPRT, 7804K115_Stainless Steel Ball Bearing.SLDPRT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]
2026-03-05 Changed MCP
    [3417-4008-0016 assembly.SLDASM, 3422-0006-0020 assembly.SLDASM, FingerMCP.SLDPRT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]
2026-03-10 finger and motor supports
    [Finger_support.SLDPRT, Link_Assembly_Final.SLDASM, MB2436-Solidworks.SLDPRT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]
2026-03-10 Static DIP and updated pulley radius
    [001_miniature_ball_bearing_3_as.sldasm, 001_miniature_ball_bearing_inch.sldasm, FingerLink.SLDPRT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]
2026-03-10 New parts for splay
    [1516-4008-0400.SLDPRT, 1516-4008-0400.STEP, 3422-4008-0020 assembly.SLDASM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]
2026-03-10 Prefinalized MCP
    [1516-4008-0480.SLDPRT, 1516-4008-0480.STEP, 17mmOD_Flanged.SLDPRT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]
2026-03-10 Updated snap fit pin retention and pulley sizing
    [7678N193_Music Wire Steel Extension Spring with Hook Ends.SLDPRT, 91585A465_18-8 Stainless Steel Dowel Pin.SLDPRT, FingerLink.SLDPRT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]
2026-03-10 Added motors
    [283856_ec-max22_25w.SLDPRT, 283856_ec-max22_25w.stp]
2026-03-10 Another MCP Revision
    [1516-4008-0500.SLDPRT, 1516-4008-0500.STEP, 1516-4008-0560.SLDPRT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]
2026-03-10 Updated code
    [Capstone.kicad_sch, Encoder.kicad_pcb, Encoder.kicad_sch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]
2026-03-10 load cell assembly and splay mount assembly
    [283856_ec-max22_25w.stp, 283856_ec-max22_25w.stp.SLDPRT, 3136N274_T-Slotted Framing.SLDPRT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]
2026-03-10 Create Assembly 1.step
    [Assembly 1.step]
2026-03-11 Progress on tension mount
    [370776_GP22HP_3NM_3ST_KL.SLDPRT, 370776_GP22HP_3NM_3ST_KL.stp, 3_pulley_tension_load_cell.SLDPRT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]
2026-03-11 What's going on?
    [0.25-20 screws.SLDPRT, 166933_GP32C-2st.sldprt, 47065T216_Corner Brace.SLDPRT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]
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2026-03-11 Static DIP for second phalange
    [FingerLink.SLDPRT, FingerMCP.SLDPRT, Fingertip Phalange.SLDPRT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]
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2026-03-11 Reworked splay spacers
    [BearingMCPSpacer.SLDPRT, FingerBase.SLDPRT, Link_Assembly_Final.SLDASM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]
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2026-03-11 Tendon route slot and MCP flex hardstop
    [1942N53_Corrosion-Resistant Extension Springs with Hook Ends.SLDPRT, 1942N54_Corrosion-Resistant Extension Springs with Hook Ends.SLDPRT, FingerLink.SLDPRT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]
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2026-03-12 Idek what's broken
    [Assem1.SLDASM, Gearbox_Face_Mount.SLDPRT, Link_Assembly_Final.SLDASM]
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2026-03-13 redesigned splay mount for new gearbox and for metric screws
    [166930_GP32C-1st.stp, 166933_GP32C-2st.stp, 166939_GP32C-3st.stp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]
2026-03-14 fix weird mating
    [Gearbox_Face_Mount.SLDPRT]
2026-03-14 fix screws
    [splay_base_plate.SLDPRT]
2026-04-02 removed parallel tensioning and replaced with idler pulley
    [1121-0002-0072.STEP, 1524-0001-0001 assembly.STEP, 3413-0001-0001.STEP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]
2026-04-03 Redesigned mounting
    [3_pulley_tension_load_cell.SLDPRT, Assem1.SLDASM, EndSpacer.SLDPRT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]
2026-04-03 sdf files for reduced assembly
    [BearingMCPSpacer.sdf, FingerBase.sdf, FingerLink.sdf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]
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2026-04-03 Changed name for Motor Mounts
    [80-20 _base_finger_supports.SLDPRT, 80-20_vertical_finger_supports.SLDPRT, EndSpacer.SLDPRT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]
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2026-04-04 Fixed the fire
    [Gearbox_Face_MountV2.SLDPRT, motors_assembly_updated.SLDASM, new_assembly_finger.SLDASM]
2026-04-08 main links mass overwrite in solidworks
    [FingerBase.SLDPRT, FingerMCP.SLDPRT, Fingertip Phalange.SLDPRT]
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2026-04-08 Finger look like finger
    [7804K145_Corrosion-Resistant 440C Stainless Steel Ball Bearing.SLDPRT, FingerBase.SLDPRT, FingerLink.SLDPRT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]
2026-04-08 Flipped pulley
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2026-04-09 assembly reset
    [7804K145_Corrosion-Resistant 440C Stainless Steel Ball Bearing.SLDPRT, Link_Assembly_Final.SLDASM, MCP Splay Wraparound Pulley.SLDPRT]
2026-04-09 changing bearing and timing pulley materials
    [001_miniature_ball_bearing_inch.sldasm, 17mmOD_Flanged.SLDPRT, 3422-4008-0030.SLDASM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]
2026-04-10 Updated Tendon width and MCP clearance
    [FingerBase.3mf, FingerBase.SLDPRT, FingerBase.STL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]
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2026-04-17 Tension sensing and motor mount manufacturability
    [1609-0610-0004.SLDPRT, 90695A033_Medium-Strength Steel Thin-Profile Hex Nut.SLDPRT, 92981A144_Alloy Steel Shoulder Screws.SLDPRT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]
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2026-04-17 fixed tendon sensor heights
    [LoadCellAssemblyV2.SLDASM, LoadCellPlateMCPTendon.SLDPRT, LoadCellPlatePIPTendon.SLDPRT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]
2026-04-17 added tension sensor mount holes
    [LoadCellPlateMCPTendon.SLDPRT, LoadCellPlatePIPTendon.SLDPRT, MCPTensionSensorAssembly.SLDASM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]
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2026-04-17 Redesigned mount, surely for the last time
    [Gearbox_Face_MountV2.SLDPRT, LoadCellPlateMCPTendon.SLDPRT, LoadCellPlatePIPTendon.SLDPRT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]
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2026-04-21 Figured out new motor pulleys - potentially deleted Josh's work
    [Assem1.SLDASM, Gearbox_Face_MountV2.SLDPRT, NewMotorPulley.SLDPRT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]
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2026-04-21 Fixed stuff
    [3_pulley_tension_load_cell.SLDPRT, LoadCellPlateMCPTendon.SLDPRT, LoadCellPlatePIPTendon.SLDPRT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]
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2026-04-22 Finger spring mounting changes
    [FingerLink.SLDPRT, FingerMCP.SLDPRT, Fingertip Phalange.SLDPRT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]
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2026-05-02 Finished some finger changes
    [FingerLinkExperimental.SLDPRT, FingerMCP.SLDPRT, Gearbox_Face_MountV2.SLDPRT]
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2026-05-05 Pin movement new hardstop
    [FingerLinkExperimental.SLDPRT, FingerMCP.SLDPRT, MCP Splay Wraparound Pulley.SLDPRT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]
2026-05-05 Added grooves, and new closed MCP splay base. Also changed termination style on pulley.
    [AngledFingerBaseNoSnapfit.SLDPRT, FingerLinkExperimental.SLDPRT, FingerMCP.SLDPRT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]
2026-05-05 Changed the motor pulley a bit
    [NewMotorPulley.SLDPRT]
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2026-05-06 power demo mostly done
    [step_data_cool_flexion.csv, step_data_splay_only.csv]
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2026-05-18 3DP splay and flex mounts
    [Fingertip Phalange.SLDPRT, Splay Mount.SLDPRT]
2026-05-18 Splay rework to re add snap fit
    [AngledFingerBase.SLDPRT, AngledFingerBaseNewSnapfitFemale.SLDPRT, AngledFingerBaseNewSnapfitMale.SLDPRT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]
2026-05-20 force fixes and starting kinematics
    [kinematics.cpp, kinematics.h, motors.cpp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]
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2026-05-21 Revert "Merge branch 'main' of https://github.com/eatmelonnnn/RDS-2026---Minimalist"
    This reverts commit 883e1484304e175d3b4adfd648e5949d44f51669, reversing
    changes made to a4f640ebd322d30c9f0196dbf41a23721d0c68da.
    [AngledFingerBaseNewSnapfitFemale.SLDPRT, AngledFingerBaseNewSnapfitMale.SLDPRT, AngledFingerBaseNoSnapfit.SLDPRT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]
2026-05-21 Reapply "Merge branch 'main' of https://github.com/eatmelonnnn/RDS-2026---Minimalist"
    This reverts commit 2f54a51d8f4bcf68ea62a4f5b891c3c471be51b2.
    [AngledFingerBaseNewSnapfitFemale.SLDPRT, AngledFingerBaseNewSnapfitMale.SLDPRT, AngledFingerBaseNoSnapfit.SLDPRT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]
2026-05-21 Fixing messed up merge
    [kinematics.cpp]
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2026-06-10 clean up electrical folder
    [data1.csv, flex_ext_log_2.csv, flex_ext_log_3.csv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]
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
